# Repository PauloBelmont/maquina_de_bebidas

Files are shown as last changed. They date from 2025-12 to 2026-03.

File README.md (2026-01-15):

# Automated Coffee & Tea Machine (ESP32 + Nextion)

## 📚 About This Project

This project was developed at the **Federal University of Roraima (UFRR)**, in the **Maloca das iCoisas Laboratory**, as part of the course **COMP 923 - Embedded Systems**, under the guidance of [**Prof. Herbert Rocha**](https://github.com/hbgit).

---

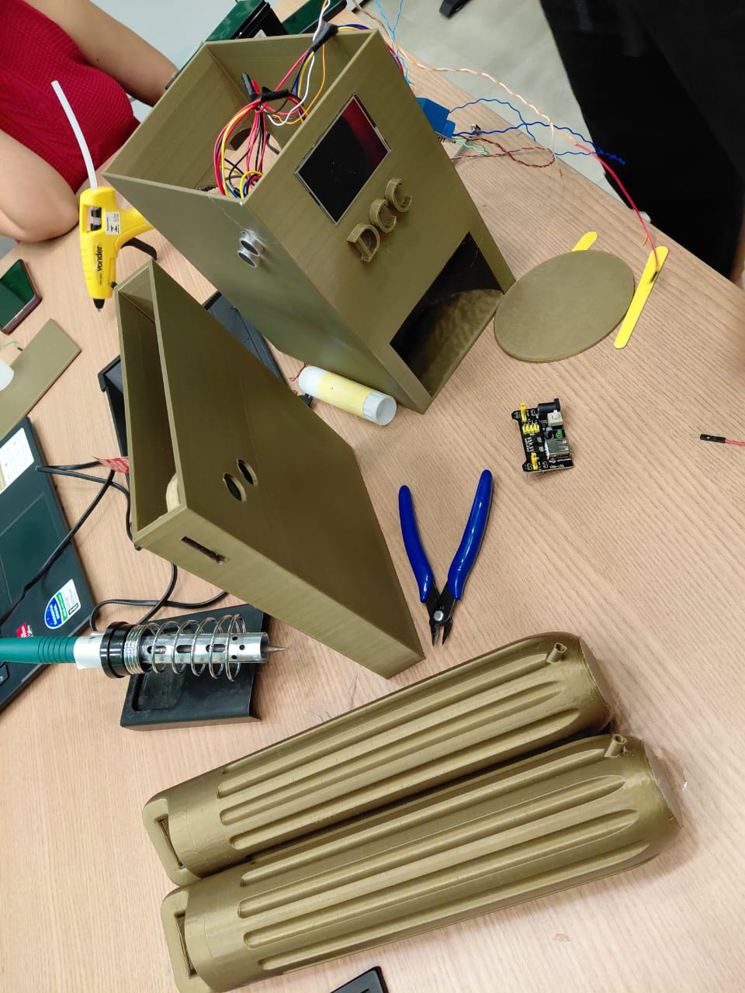
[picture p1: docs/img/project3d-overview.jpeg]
3D-printed coffee and tea vending machine prototype disassembled on a workbench, showing the main enclosure with screen and DCC logo, side panels, cylindrical reservoirs, wiring and assembly tools


This project is an embedded system for a hot beverage vending machine (coffee and tea). It uses an ESP32 for logic control, ultrasonic sensors for process detection, and a Nextion display for the Human-Machine Interface (HMI).

## 📂 Contents

The project directory structure is organized as follows:

* **`docs/`** - Project documentation, including requirements reports, circuit diagrams, and operation manuals.
* **`src/`** - Includes the Nextion interface project files (`.HMI`, `.tft`) and the source code (`.ino`) used on the ESP32.

## 🛠 Hardware

The physical project consists of the following components:

**Control & Interface**
* 1x ESP32 Devkit V1 Board
* 1x Nextion NX3224T024_011 Display (Touchscreen)

**Sensors & Actuators**
* 2x HC-SR04 Ultrasonic Sensors (Coin and Cup detection)
* 2x Peristaltic Pumps - Rohs Grothen G328
* 1x Relay Module SRD-05VDC-SL-C (Pump/Power control)

**Power & Structure**
* 1x Valve Regulated Lead-Acid (VRLA) Battery 12V
* 2x 3D Printed Cases (PLA) for main structure and coin mechanism
* 1x 3D Printed Plate (PLA)
* 2x 3D Printed Liquid Reservoirs (PLA)
* Hoses and Dispensing Nozzles

## Software Used

* **Arduino IDE:** For ESP32 firmware programming.
* **Nextion Editor (LTS):** For graphical interface development.
* **TinkerCad:** For 3D modeling and/or circuit simulation.
* **Doxygen:** For source code documentation.

## How it Works

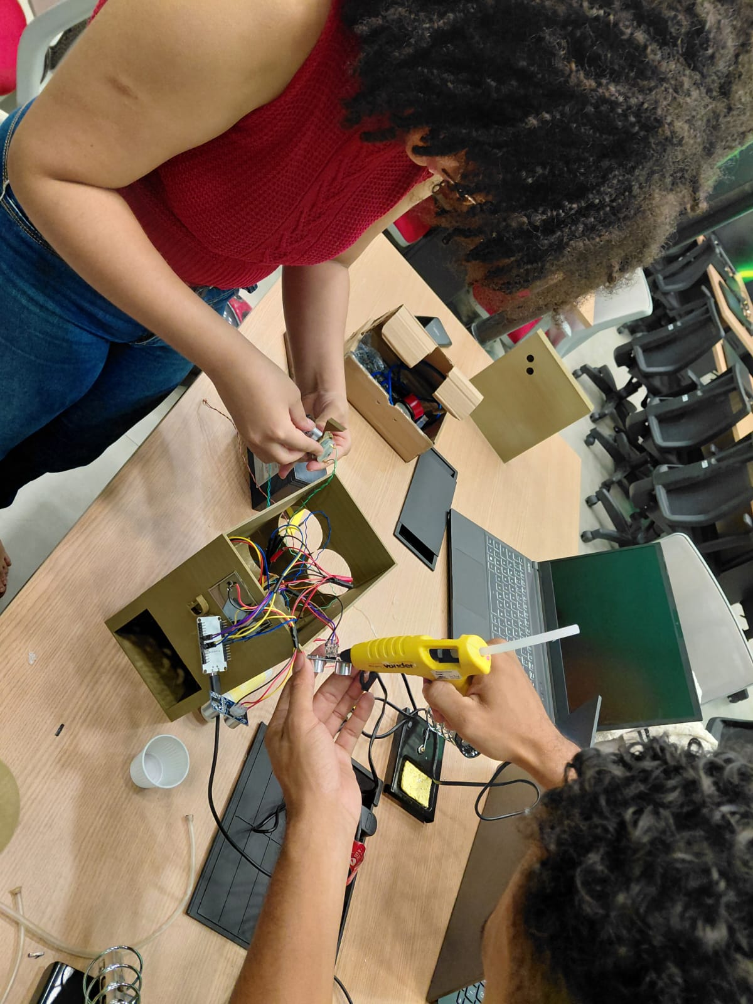
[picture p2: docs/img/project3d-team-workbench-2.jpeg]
Team members assembling the 3D-printed coffee machine structure and gluing components during the prototype build


The code operates based on a Finite State Machine (FSM), ensuring the process follows a safe logical order:

1.  **Start:** The system initializes and waits for a coin to be inserted.
2.  **Coin Insertion:** The HC-SR04 sensor (Pins X/Y) detects a coin drop.
3.  **Cup Placement:** The second HC-SR04 sensor (Pins X/Y) verifies a cup is in the dispenser.
4.  **Selection:** The user selects "Coffee" or "Tea" on the Nextion screen.
5.  **Preparation:** The corresponding pump is activated for a set duration , updating a progress bar on the screen.
6.  **Completion:** The system waits for the cup to be removed before resetting to the start state for a new cycle.

## 🔌 Pinout (ESP32)

| Component | ESP32 Pin | Function |
| :--- | :--- | :--- |
| **Coin Trig** | GPIO 32 | Coin Sensor Trigger |
| **Coin Echo** | GPIO 33 | Coin Sensor Echo |
| **Cup Trig** | GPIO 19 | Cup Sensor Trigger |
| **Cup Echo** | GPIO 18 | Cup Sensor Echo |
| **Coffee Relay** | GPIO 25 | Coffee Pump Activation |
| **Tea Relay** | GPIO 26 | Tea Pump Activation |
| **Nextion RX** | GPIO 16 | RX2 (Serial) |
| **Nextion TX** | GPIO 17 | TX2 (Serial) |

## Authors

- **Andersson Silva Pereira** — *andersonwya4@gmail.com*
- **Matheus Rebouças de Lima** — *mthsbusiness91@protonmail.com*
- **Paulo César Pereira Belmont** — *paulopereira737@hotmail.com*
- **Sarah Evelyn do Vale Silva** — *sarahevelyn.scholar@gmail.com*

## Additional Photos

More photos of the 3D-printed parts, internal circuits and assembly process are available in the [`docs/img/`](docs/img/) folder.

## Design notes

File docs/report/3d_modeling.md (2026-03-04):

# 3D Modeling Documentation (Tinkercad)

## 1. Main Enclosure (3D Model Assembly)
This section documents the main enclosure design, modeled entirely in Tinkercad. This 3D structure is the chassis designed to house the system's components, including mounting points for the UI, dispensing area, fluid routing, and internal supports.

### Purpose
The main enclosure integrates:
- The user interface (touchscreen opening).
- The dispensing window (cup insertion area).
- Internal mounts for reservoirs, pumps, and tube routing.
- The ultrasonic sensor used for coin detection (installed inside the main enclosure, aligned to detect the coin passing through the chute path).

### Images
| Top View / Internal Layout | Alternate Image |
| :---: | :---: |
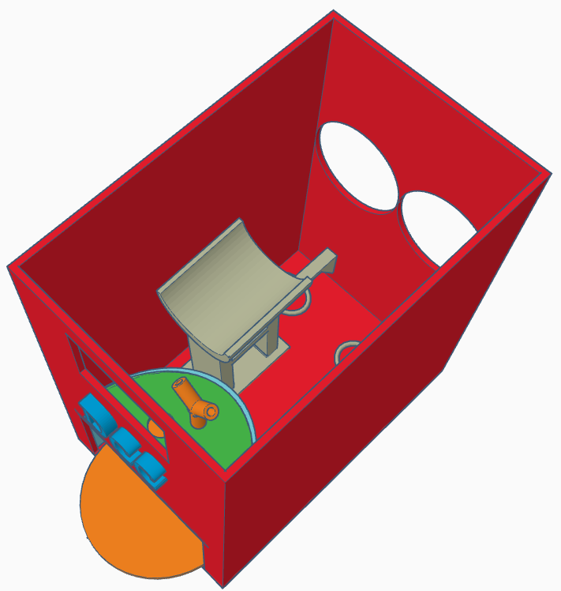
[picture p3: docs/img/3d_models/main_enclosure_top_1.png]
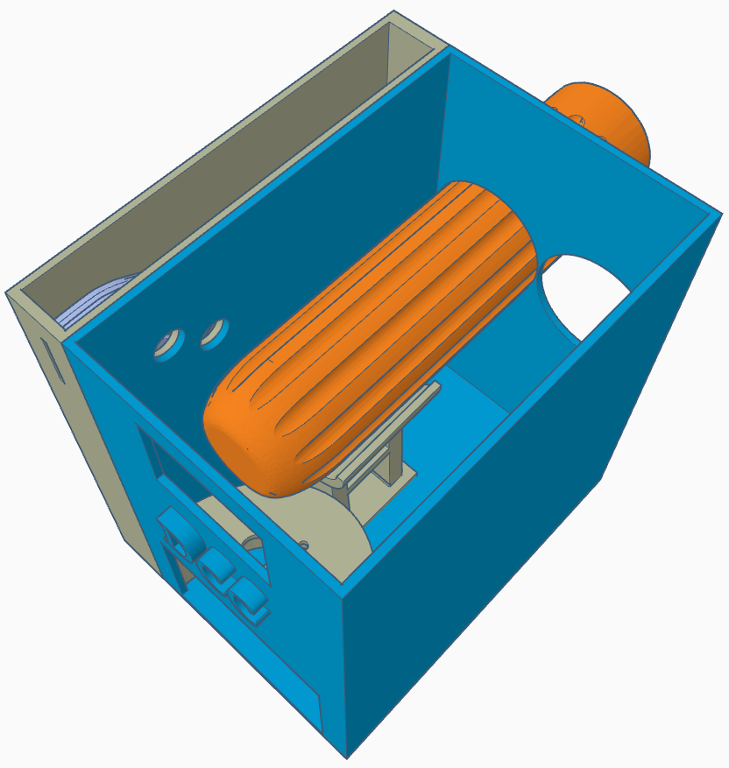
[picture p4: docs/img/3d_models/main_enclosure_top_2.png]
|  |  |

**Front View (UI & Dispensing Area):**
<div align="center">
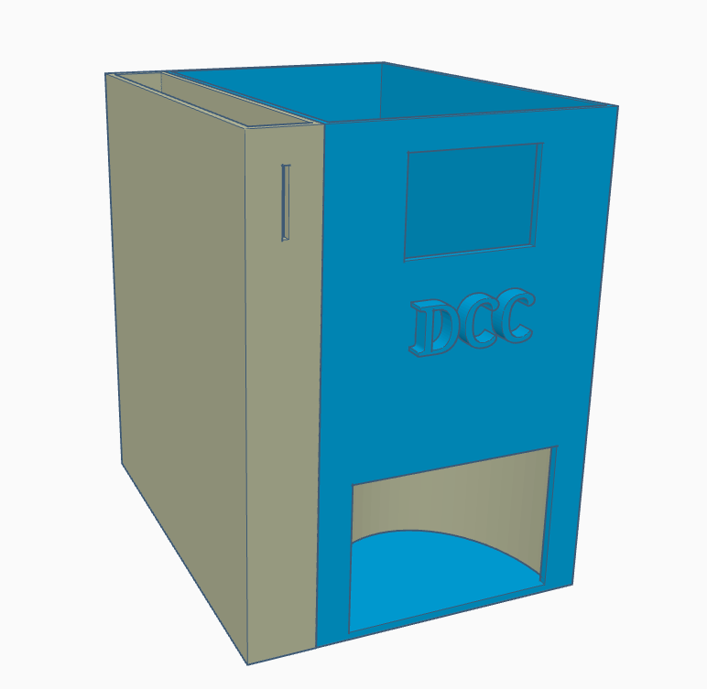
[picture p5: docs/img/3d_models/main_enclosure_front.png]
  
</div>

---

## 2. Coin Box Module (Side Module)
The coin box (side module) is the entry point for coins. It is physically attached to the main enclosure and is responsible for guiding the coin into the sensing region.

### Images
| External View | Internal View |
| :---: | :---: |
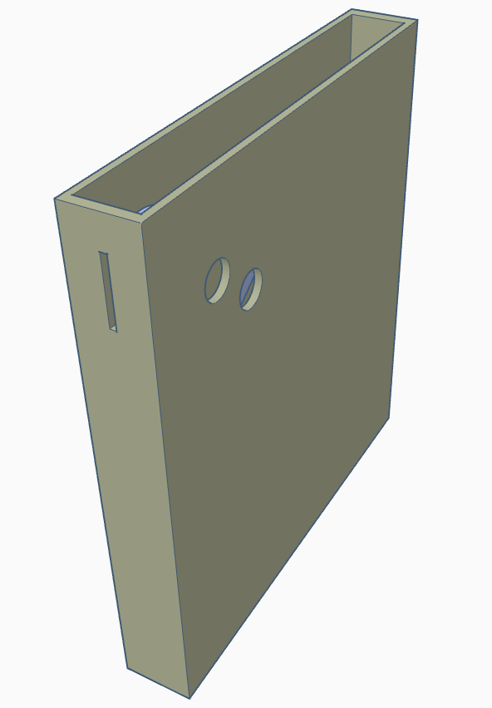
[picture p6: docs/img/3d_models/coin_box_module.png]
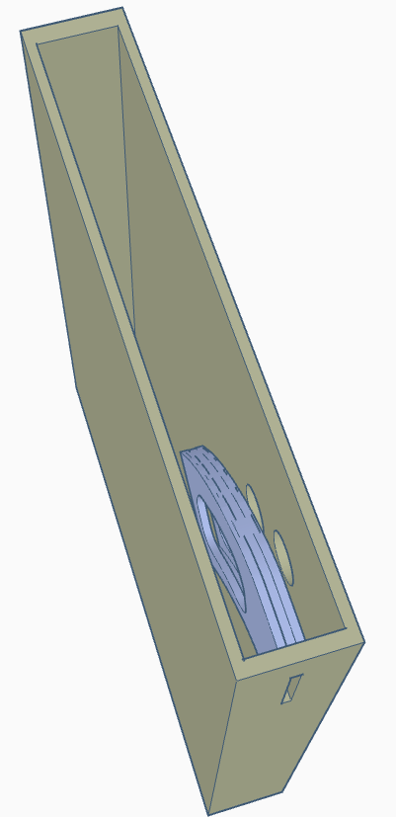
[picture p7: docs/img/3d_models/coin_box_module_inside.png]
|  |  |

---

## 3. Coin Chute ("Toboggan") + Coin Detection
Inside the coin box, a gravity-fed chute (toboggan) guides the coin along a controlled path. The chute is designed so that, as the coin slides down, it passes through a region where an ultrasonic sensor inside the main enclosure can detect it.

### Sensor Positioning
- The ultrasonic sensor used for coin detection is installed inside the main enclosure and is oriented at approximately **45°**, aimed toward the coin path to produce a reliable distance change when a coin passes.

### Images
| Front View | Side View |
| :---: | :---: |
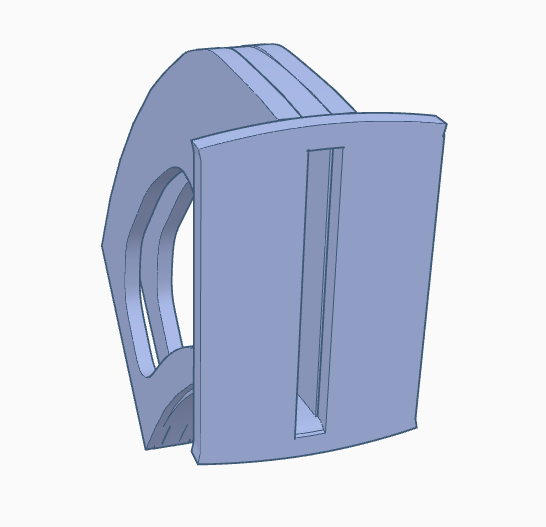
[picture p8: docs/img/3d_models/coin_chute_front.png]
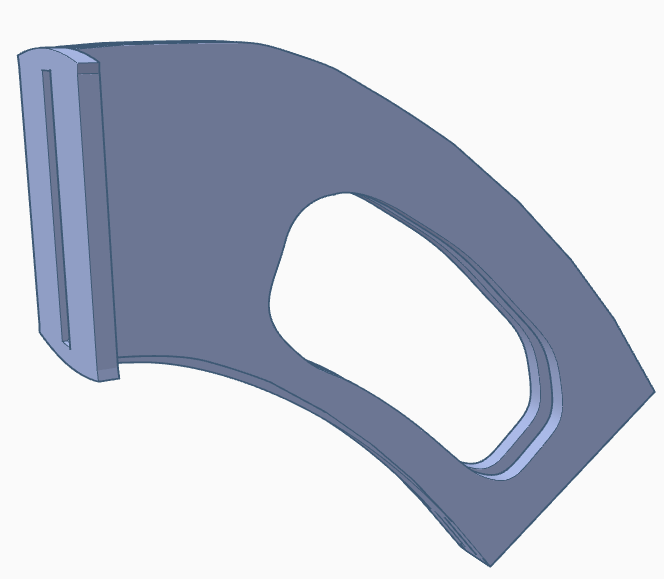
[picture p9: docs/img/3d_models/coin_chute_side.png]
|  |  |

---

## 4. Cup Insertion Area + Cup Base + Cup Presence Sensor
This subsystem guarantees correct cup positioning before dispensing and adds safety/automation by verifying cup presence.

### Cup Insertion (Dispensing Window)
The front-bottom opening is where the user inserts the cup. The geometry is designed to guide the cup into a stable dispensing position.

### Cup Base (Support Plate)
A base/plate is included to support the cup and keep it aligned under the outlet (Y-connector output).

### Cup Presence Ultrasonic Sensor (Top Hole)
A second ultrasonic sensor is used to detect whether a cup is present. A dedicated hole/opening is placed **on the upper part** of the cup insertion area to mount this sensor, facing the cup region.

### Images
**Cup Station & Y-Connector Alignment:**
<div align="center">
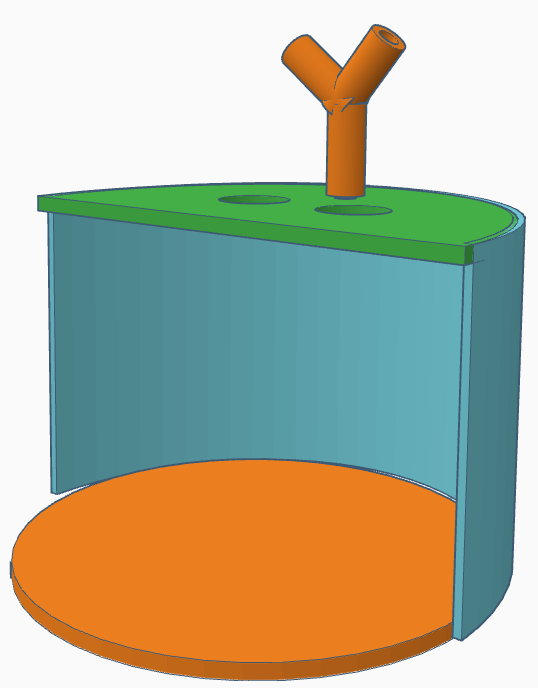
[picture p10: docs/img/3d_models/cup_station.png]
  
</div>

| Sensor Holes (Bottom View) | Rear View |
| :---: | :---: |
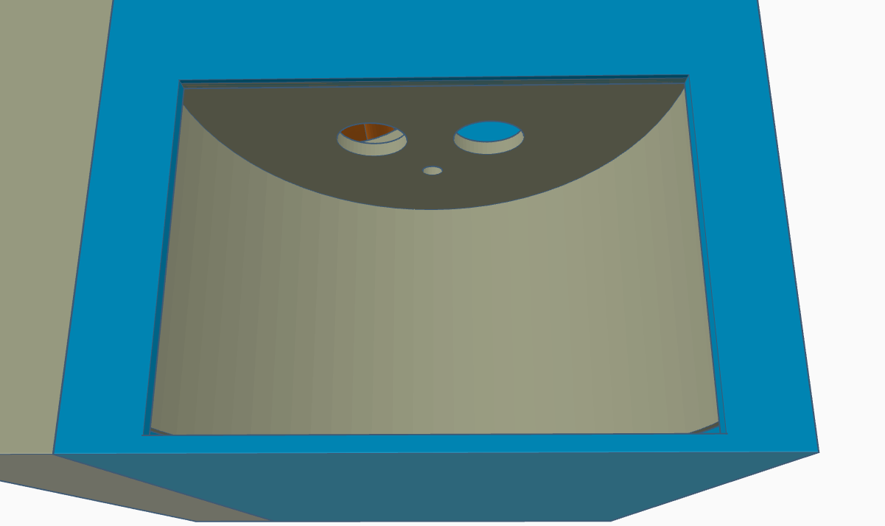
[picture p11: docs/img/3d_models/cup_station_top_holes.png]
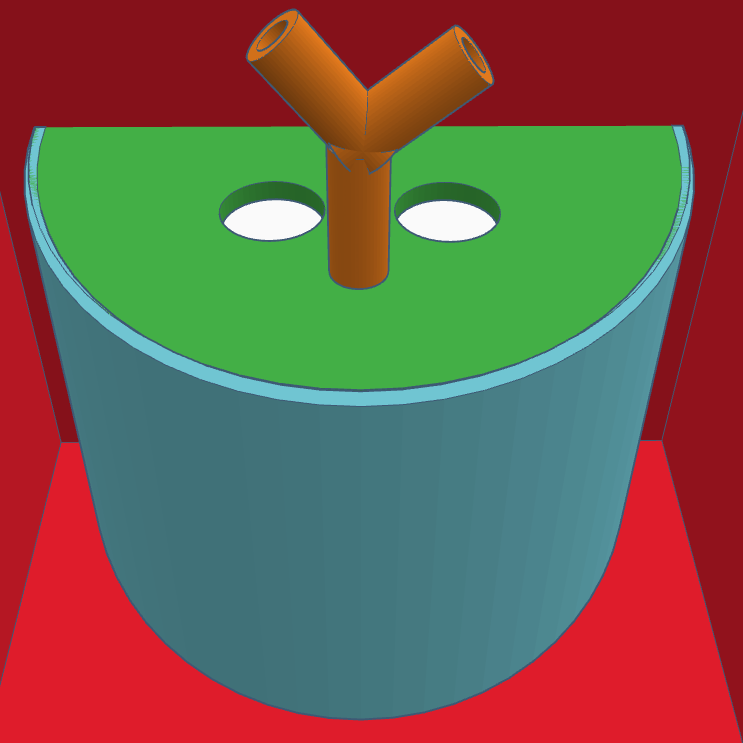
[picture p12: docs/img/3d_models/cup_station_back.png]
|  |  |

---

## 5. Y-Connector (Fluid Convergence and Alignment)
The Y-connector is a custom printed part that merges two fluid lines (tea and coffee) into a single outlet. It is positioned so the combined output falls precisely into the cup at the center of the cup station, minimizing splash and misalignment.

### Images
| Placement Overview | Internal Channel View |
| :---: | :---: |
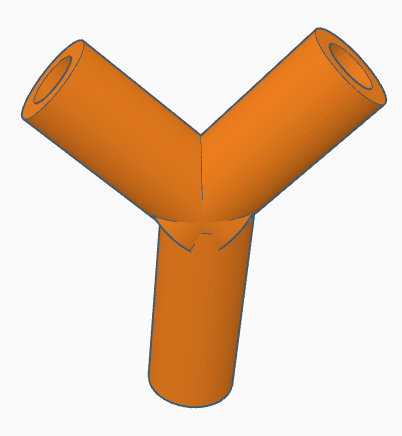
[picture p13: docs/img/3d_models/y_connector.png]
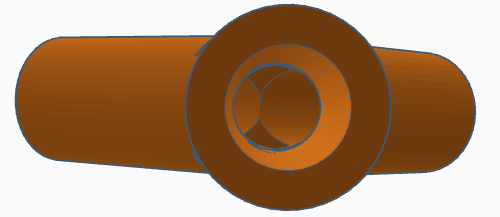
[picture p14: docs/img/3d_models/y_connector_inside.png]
|  |  |

---

## 6. Reservoir Support (Tea & Coffee Holders)
An internal support structure stabilizes the tea and coffee reservoirs.

### Images
| Structure Overview | Side Profile |
| :---: | :---: |
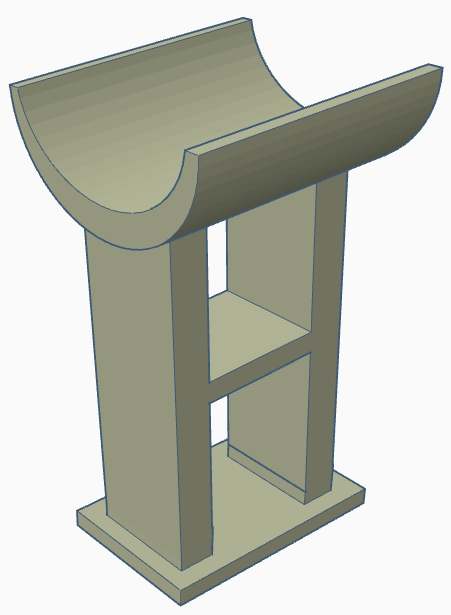
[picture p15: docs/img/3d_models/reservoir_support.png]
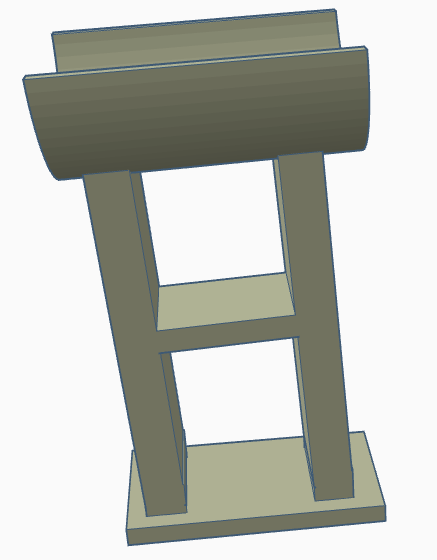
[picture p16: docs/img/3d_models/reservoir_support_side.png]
|  |  |

---

## 7. Pump Motor Mounts (Liquid Pump Supports)
Two smaller mounts are used to hold the pump motors responsible for pulling liquids from the reservoirs. These mounts constrain movement and reduce vibration, keeping tube routing stable and repeatable.

### Images
| Mount Isometric View | Mount Front View |
| :---: | :---: |
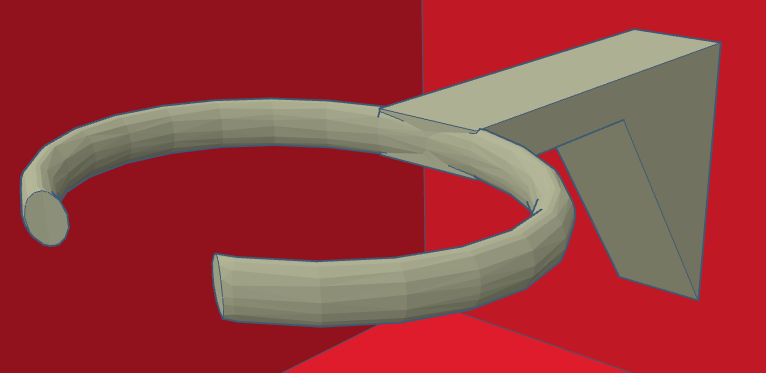
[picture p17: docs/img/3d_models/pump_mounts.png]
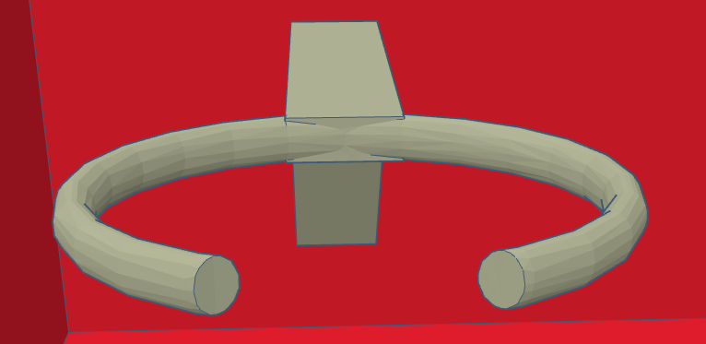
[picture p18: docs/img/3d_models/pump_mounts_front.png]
|  |  |

---

## 8. Coffee Liquid Reservoir (Inspired Design)
The coffee liquid reservoir was inspired by an existing model published on MakerWorld:
[https://makerworld.com/en/models/155504-keychain-container-pill-storage-bottle#profileId-836561](https://makerworld.com/en/models/155504-keychain-container-pill-storage-bottle#profileId-836561)

### Changes from the Original Model
- **Vertical Scaling:** The primary modification was increasing the height to expand fluid capacity.
- **Diameter Adjustment:** Both the top and bottom parts were adjusted to a diameter of **61 mm** to fit the machine's internal supports.
- The cap design and threading mechanism remain identical to the original author’s model.

### Notes
This design choice was made to increase usable volume while preserving the proven geometry of the original container (including its lid fit and mechanical structure).

### Images
| Top Part (Isometric) | Top Part (Top View) |
| :---: | :---: |
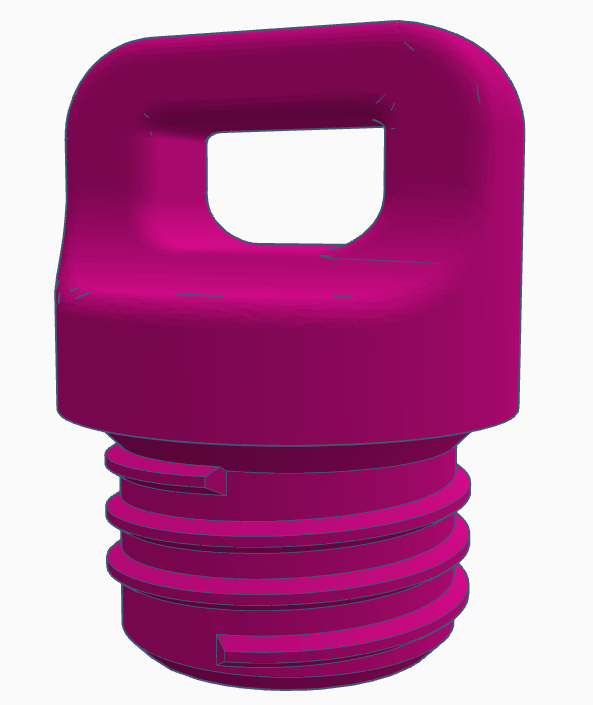
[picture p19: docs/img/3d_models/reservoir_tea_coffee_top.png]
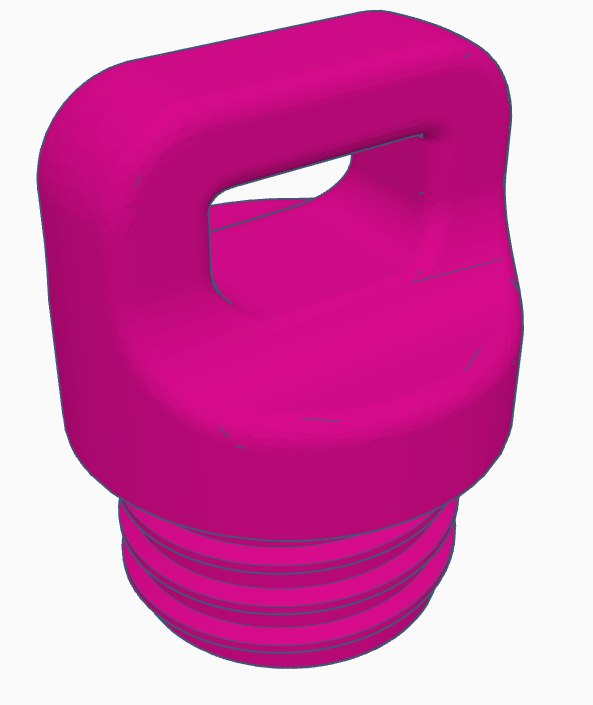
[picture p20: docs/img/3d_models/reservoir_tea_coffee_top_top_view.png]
|  |  |

| Bottom Part (Isometric) | Bottom Part (Top View) |
| :---: | :---: |
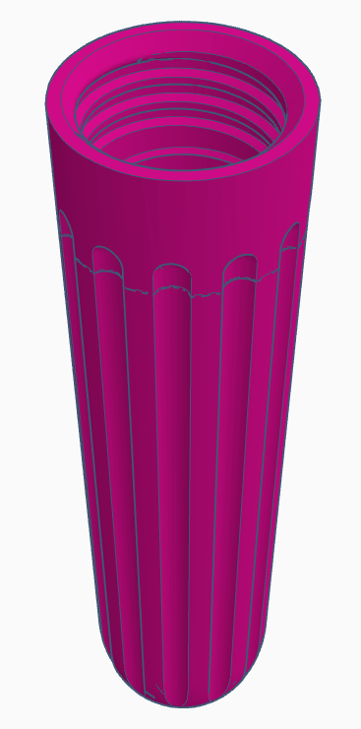
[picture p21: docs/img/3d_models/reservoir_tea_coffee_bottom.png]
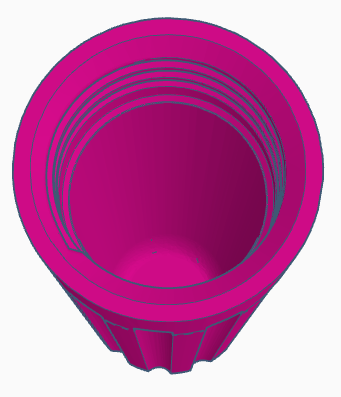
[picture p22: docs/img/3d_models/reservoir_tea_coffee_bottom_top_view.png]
|  |  |

---

## 9. Downloads (STL Files)
All the STL files necessary for 3D printing these components are available in the repository. You can find them in the following directory:

📂 **[3D Models Folder](../../src/stl/)**

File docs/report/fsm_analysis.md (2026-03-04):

# ⚙️ Finite State Machine (FSM) Analysis

**Project:** Automated Hot Beverage Machine
**Module:** Firmware Logic (ESP32)

## 1. Overview

The system control logic is implemented using a **Finite State Machine (FSM)**. This approach ensures that the machine is always in a known, deterministic state, preventing invalid operations (e.g., pouring coffee without a cup or dispensing two drinks for one coin).

The FSM manages the entire lifecycle of a transaction: from initialization and coin detection to beverage dispensing and system reset.

***

## 2. State Diagram Representation

The following diagram represents the logical flow implemented in the firmware:

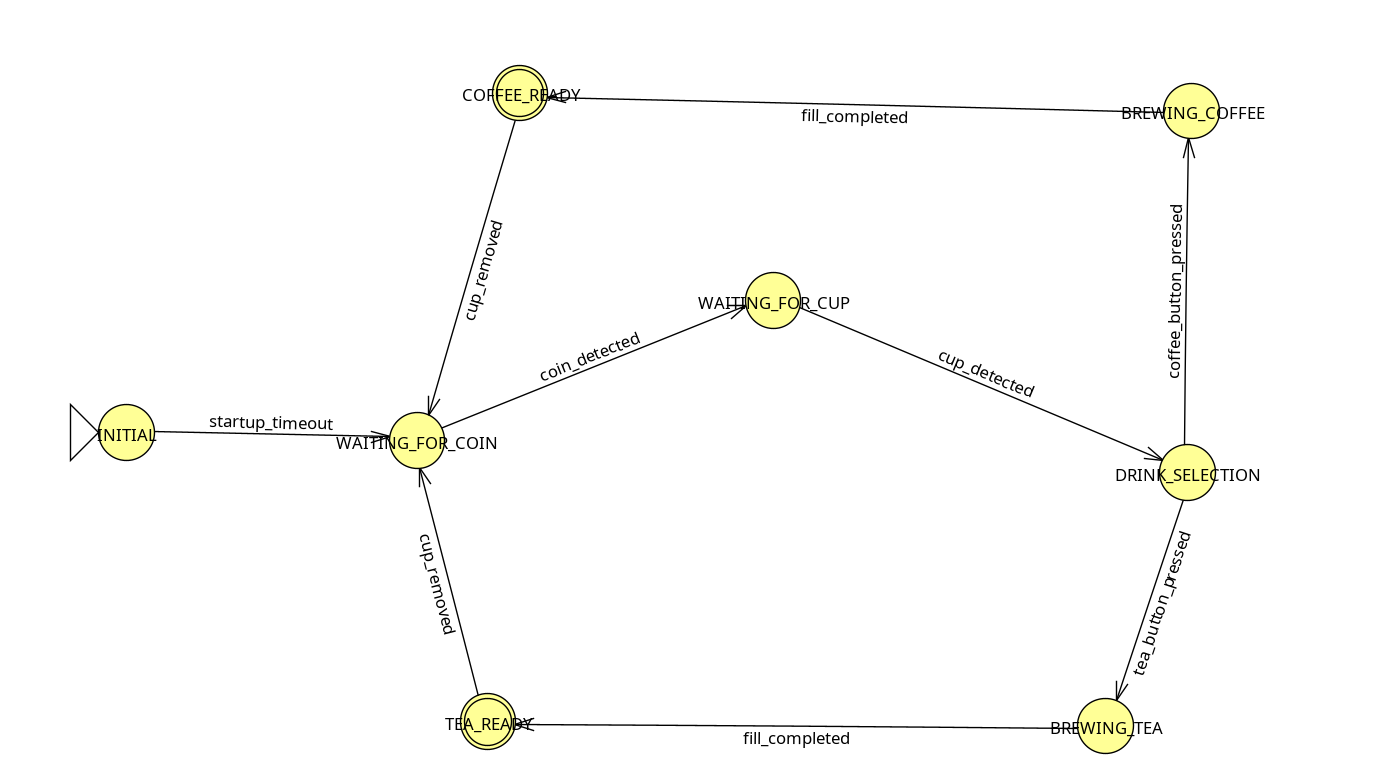
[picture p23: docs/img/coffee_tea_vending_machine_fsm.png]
State Machine Diagram showing the transition flow from initialization to coin detection, cup verification, drink selection, and final dispensing loop


***

## 3. Detailed State Definitions

The system consists of **7 distinct states**. Each state defines specific active sensors and permitted actions.

| State Name | Description | Active Hardware / Output |
| :--- | :--- | :--- |
| **INITIAL** | System boot, variable initialization, and sensor calibration. | Display: "Initializing..." |
| **WAITING_FOR_COIN** | The machine is idle, waiting for a user to insert a coin (token). | Sensor: Ultrasonic 1 (Coin) <br> Display: "Insert Coin" |
| **WAITING_FOR_CUP** | A coin was validated. System now waits for a cup to be placed in the dispenser area. | Sensor: Ultrasonic 2 (Cup) <br> Display: "Place Cup" |
| **DRINK_SELECTION** | Cup is present. The system unlocks the touchscreen for beverage choice. | Input: Nextion Touch (UART) <br> Display: "Select Drink" |
| **BREWING_COFFEE** | The pump for Coffee is active for a calibrated duration. | Actuator: Pump 1 (ON) <br> Display: "Brewing Coffee..." |
| **BREWING_TEA** | The pump for Tea is active for a calibrated duration. | Actuator: Pump 2 (ON) <br> Display: "Brewing Tea..." |
| **COFFEE/TEA_READY** | Dispensing is done. System waits for the user to take their drink before resetting. | Sensor: Ultrasonic 2 (Cup) <br> Display: "Enjoy!" |

***

## 4. Transition Logic Table

Transitions are triggered by specific **events** (sensor readings, timers, or user inputs).

| Current State | Event / Condition | Next State | Justification |
| :--- | :--- | :--- | :--- |
| `INITIAL` | `startup_timeout` (e.g., 3s) | `WAITING_FOR_COIN` | Allows sensors to stabilize before reading. |
| `WAITING_FOR_COIN` | `coin_detected` (Distance < Threshold) | `WAITING_FOR_COIN` | Payment validated. Proceed to preparation. |
| `WAITING_FOR_CUP` | `cup_detected` (Distance < Threshold) | `DRINK_SELECTION` | Safety check: Ensures a container is present. |
| `DRINK_SELECTION` | `coffee_button_pressed` (UART 'A') | `BREWING_COFFEE` | User choice: Coffee. |
| `DRINK_SELECTION` | `tea_button_pressed` (UART 'B') | `BREWING_TEA` | User choice: Tea. |
| `BREWING_COFFEE` | `fill_completed` (Timer) | `COFFEE_READY` | Volumetric control by time (e.g., 5000ms). |
| `BREWING_TEA` | `fill_completed` (Timer) | `TEA_READY` | Volumetric control by time. |
| `COFFEE/TEA_READY` | `cup_removed` (Distance > Threshold) | `WAITING_FOR_COIN` | Reset cycle for next customer. |

***

## 5. Safety & Reliability Features

The FSM implementation provides critical safety mechanisms:

1.  **Interlock Safety:** It is impossible to activate a pump (Dispensing state) directly from the Idle state. The path *must* include Coin Validation → Cup Verification.
2.  **Spill Prevention:** The `WAITING_FOR_CUP` state acts as a physical barrier. If a user inserts a coin but forgets the cup, the machine waits indefinitely and does not dispense liquid into the tray.
3.  **Debouncing:** Sensor transitions (like `coin_detected`) typically implement software debouncing to prevent false positives from sensor noise.
4.  **Sequential Reset:** The machine only returns to `WAITING_FOR_COIN` after the previous user has removed their finished drink (`cup_removed`), preventing the next user from accidentally interacting with a finished cycle.

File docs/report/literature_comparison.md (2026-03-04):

# 📚 Comparative Literature Review

The following section presents **two comparative tables**:

1.  **Commonalities** shared across all four analyzed articles.
2.  **Key Differences** distinguishing each approach.

For clarity, the articles are identified as follows:

*   **A1** – Innovation Station (3D printing vending machine)
*   **A2** – Didactic Vending Machine (Arduino-based)
*   **A3** – Energetically Efficient Vending Machine
*   **A4** – RPJ 2014 (Vending/Mechatronic systems)

***

## 🔹 Table 1 — Commonalities Across All Articles

| Common Point | Description |
| :--- | :--- |
| **Vending Machine Usage** | All projects utilize a vending machine structure as the system baseline. |
| **Process Automation** | Product dispensing is fully automated. |
| **Mechatronic Integration** | They combine mechanics, electronics, and software engineering. |
| **Embedded Systems** | Use of microcontrollers or computational control units. |
| **Physical Prototyping** | All papers present functional physical prototypes. |
| **Modeling & Simulation** | Utilization of simulation, CAD, or virtual modeling tools. |
| **Focus on Innovation** | Proposals offer improvements over traditional vending machines. |
| **Efficiency Analysis** | Evaluation of performance, consumption, reliability, or optimization. |
| **Practical Application** | The systems are designed for deployment in real-world environments. |
| **Academic Approach** | The projects possess a scientific or educational character. |

**Sources:** A1, A2, A3, and A4

***

## 🔹 Table 2 — Differences Between Articles

| Article | Primary Objective | Key Differentiator | Focus Area |
| :--- | :--- | :--- | :--- |
| **A1** | Democratize 3D printing | Automatic removal via thermal cycling + Web portal | Additive manufacturing & Education |
| **A2** | Engineering education | Arduino, SMS stock alerts, change return system | Embedded systems & Didactics |
| **A3** | Energy sustainability | Solar power supply & consumption optimization | Energy efficiency & Mechatronics |
| **A4** | Technical/Industrial app | Emphasis on reliability and control logic | Industrial automation |

**Sources:** A1, A2, A3, and A4

***

## 🔹 Quick Interpretation

*   All articles address **automated vending machines**, but with distinct focuses:
    *   **A1** focuses on **3D printing accessibility**.
    *   **A2** focuses on **teaching with Arduino**.
    *   **A3** focuses on **renewable energy and efficiency**.
    *   **A4** focuses on **industrial robustness**.

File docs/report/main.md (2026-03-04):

# Technical Report

Project: Automated Hot Beverage Machine (Coffee and Tea)
========================================================

<h3>Repository: <a href="https://github.com/PauloBelmont/maquina_de_bebidas">PauloBelmont/maquina_de_bebidas</a></h3>

**Authors:** Andersson Silva Pereira, Matheus Rebouças de Lima, Paulo César Pereira Belmont, Sarah Evelyn do Vale Silva ([GitHub][1])
**License:** MIT ([GitHub][1])
**Date:** *January / 2026*
**CAPES Category:** Prototype, system, artifact, or computational process with functional validation.

**Report Objective:** Document technological architecture, innovation, components, and system operation.

**Justification:**

- Functional embedded system, not merely conceptual;
- Integrates hardware–software integration;
- Possesses technical documentation (report, UML diagrams, architecture);
- Is reproducible and subject to experimental validation.

---

## 📌 1. Project Overview

The &quot;<b>Automated Hot Beverage Machine</b>&quot; project consists of an **embedded system for autonomous acquisition and preparation of hot beverages** (coffee and tea), integrating sensors, actuators, and human-machine interface (HMI). The system was developed with focus on educational applications and rapid prototyping in the context of embedded systems.

---

## 📐 2. Solution Scope

This technical report addresses:

* **Technological architecture** of the system (hardware and software);
* **Control methods and user interface**;
* **Technical innovation and technological differentiation**;
* **Relevance for R&D&I**;
* **Conclusions and evolution recommendations**.

---

### 📚 2.1 Related Work & Theoretical Analysis

To validate the architectural decisions of this project, a comparative study was conducted against four academic references (A1-A4), analyzing commonalities in embedded automation and differences in application scope (3D printing, education, energy efficiency).

*   **[📄 Read the Full Literature Comparison](literature_comparison.md)**

Furthermore, the core control logic relies on a Finite State Machine (FSM). A detailed analysis of states, transitions, and safety conditions is available in the dedicated analysis document.

*   **[⚙️ Read the FSM Logic Analysis](fsm_analysis.md)**

---

## 🏗️ 3. Technological Architecture

### 🔌 3.1 Hardware

The machine utilizes a hybrid architecture combining electronic modules, detection sensors, and user interface:

| Component | Primary Function |
| --- | --- |
| **ESP32 Devkit V1** | Main control unit (MCU) |
| **Display Nextion NX3224T024_011** | Graphical interface and touchscreen (HMI) |
| **Ultrasonic Sensors HC-SR04** | Coin insertion and cup presence detection |
| **Peristaltic Pumps** | Precise liquid dispensing |
| **Relay Module SRD-05VDC-SL-C** | Pump control / power management |
| **Power Supply (12V Battery)** | System power |
| **3D-Printed Reservoirs** | Physical liquid storage |

**Integration Description:**
The **ESP32** orchestrates all modules, receiving sensor signals and commanding dosage pumps, ensuring the machine's operation cycle executes sequentially and safely. Event detection (such as coin insertion or cup presence) is performed by ultrasound, executing periodic readings and activations according to defined states.

---

### 🧠 3.2 Software

#### 🗂️ 3.2.1 Firmware (ESP32)

The firmware is **developed in C++ for the ESP32**, with logic based on **Finite State Machine (FSM)** to control operation phases:

1. **Initialization:** sensor and display setup
2. **Coin awaiting:** ultrasonic sensor detects insertion
3. **Cup detection:** second sensor reading
4. **Beverage selection:** via touchscreen interface
5. **Dispensing:** activation of corresponding pump
6. **Cycle completion:** cup removal detection and reset

This state pattern improves safety and reliability of the preparation process.

---

### 🎨 3.2.2 Human-Machine Interface (Nextion)

The graphical interface is designed to:

* Enable intuitive beverage selection;
* Display user feedback (e.g., progress, error messages);
* Connect via UART serial to the ESP32.

The use of **Nextion** display facilitates building complex interfaces without overloading the main microcontroller.

---

## 🚀 4. Technological Innovation

This project presents innovative aspects for educational applications and prototyping:

### ✓ Finite State Machine (FSM) Usage

FSM adoption organizes control flow and ensures robustness against asynchronous events, an essential factor in reactive embedded systems.

---

### ✓ Ultrasonic Sensing

The use of **ultrasonic sensors for coin and cup detection** is more precise and less susceptible to failures than simple mechanical switches.

---

### ✓ Agile Interface with Nextion

The separation between control (ESP32) and graphical interface (Nextion) is an architectural characteristic that **improves modularity and scalability**, especially when compared with systems implementing UI directly in firmware.

---

### ✓ 3D Printing Applied to Prototyping

The use of **3D-printed components** for physical structure enables rapid adjustments and design customization, a differentiator for R&D of interactive prototypes and IoT systems.

---

## 📈 5. Innovation Characteristics and Impact

This project demonstrates **an advance in teaching embedded systems and sensory integration with actuators**. Furthermore:

* ESP32 use incorporates future connectivity (Wi-Fi/Bluetooth) for telemetry or remote control;
* Architectural modularity facilitates evolution (e.g., NFC payment, cloud integration, consumption tracking, real-time dashboards);
* Can evolve into a minimum viable product in commercial environments or events.

This foundation is comparable to beverage automation trends, where intelligent autonomous systems address automated preparation and dispensing solutions — technically relevant in the current context of automation and services. ([TecMundo][2])

---

## 🧩 6. Conceptual Diagram (Text)

```
[Ultrasonic Sensor 1]       [Ultrasonic Sensor 2]
           │                        │
           └──────> ESP32 MCU <─────┘
                    │   ↓   ↑
                    │    Nextion Display
                    ↓
           [Power Relay] ──→ [Peristaltic Pumps]
                    ↓
              Dispensing System
```

## 🔄 7. System Architecture Diagram

```
┌─────────────────────────────────────────────────────┐
│              ESP32 Firmware (FSM)                   │
│  ┌──────────┐  ┌──────────┐  ┌──────────┐          │
│  │ Sensor   │  │ Actuator │  │ Serial   │          │
│  │ Manager  │  │Controller│  │ Comm     │          │
│  └──────────┘  └──────────┘  └──────────┘          │
└────────┬──────────────┬──────────────┬──────────────┘
         │              │              │
    ┌────▼─┐       ┌────▼──┐      ┌───▼────┐
    │Sensors│      │Relay  │      │Nextion │
    │(HC-   │      │Module │      │Display │
    │SR04)  │      │       │      │(UI)    │
    └───────┘      └───┬───┘      └────────┘
                       │
                   ┌───▼─────┐
                   │ Pumps   │
                   │(Liquid) │
                   └─────────┘
```

**Componentes:**
- **ESP32:** Orquestra sensores e atuadores via FSM
- **Sensores Ultrassônicos:** Detectam moedas e xícara
- **Módulo Relé:** Controla ativação das bombas
- **Display Nextion:** Interface gráfica via UART

## 8. Sequence Diagram (Main Scenario)

```
mermaid
sequenceDiagram
    ```
    mermaid
    sequenceDiagram
        participant U as User
        participant D as Nextion Display
        participant E as ESP32
        participant S as Sensors
        participant P as Pump

        U ->> D: Interacts with interface
        S ->> E: Coin detected
        E ->> D: Requests cup insertion
        S ->> E: Cup detected
        U ->> D: Selects Coffee
        D ->> E: Sends command
        E ->> P: Activates coffee pump
        P -->> E: Dispensing completed
        E ->> D: Displays final message
    ```
```

---

## 🧪 9. Technical Evaluation

### ✔ Strengths

* Modularity between control and interface;
* Detection robustness and operation cycle;
* Potential for IoT extension;
* Software pattern usage (FSM).

### ⚠ Limitations

* Lack of integration with modern payment methods;
* Absence of transaction logging or telemetry;
* Current scope limited to educational prototype.

---

## 📌 10. Recommendations for Evolution

| Future Improvements | Expected Benefits |
| --- | --- |
| **NFC Payment** | Modernizes usage and accessibility  |
| **Cloud Connectivity** | Telemetry and consumption dashboards|
| **Mobile App Control** | Remote interaction and personalization|
| **Machine Learning** | Stock prediction or recommendation  |

---

## 🏁 11. Conclusion

The **Automated Beverage Machine** project is a solid example of embedded systems prototyping with **sensory integration, reactive control, and user-friendly interface**. Its modular technological architecture and use of emerging technologies make it a relevant case for **R&D&I in IoT, physical automation, and advanced prototyping**.

---

## 📚 12. References

1. Project GitHub repository: *PauloBelmont/maquina_de_bebidas* – README and code structure. ([GitHub][1])
2. Articles on ultrasonic sensors and FSM in embedded systems.
3. Comparison with autonomous beverage machines and automation trends. ([TecMundo][2])

---

[1]: https://github.com/PauloBelmont/maquina_de_bebidas "GitHub - PauloBelmont/maquina_de_bebidas: Este repositório contém todos os artefatos relacionados ao projeto maquina de chafé"
[2]: https://www.tecmundo.com.br/tecnologia/47158-10-bartenders-robos-que-fazem-drinks-tao-bem-quanto-os-humanos.htm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 "10 bartenders robôs que fazem drinks tão bem quanto os humanos | Internet"

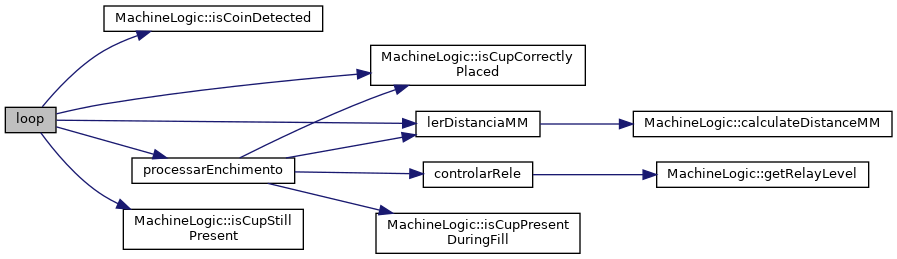
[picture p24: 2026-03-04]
docs/doxygen_output/html/dc/d3c/main_8ino_a0b33edabd7f1c4e4a0bf32c67269be2f_cgraph.png

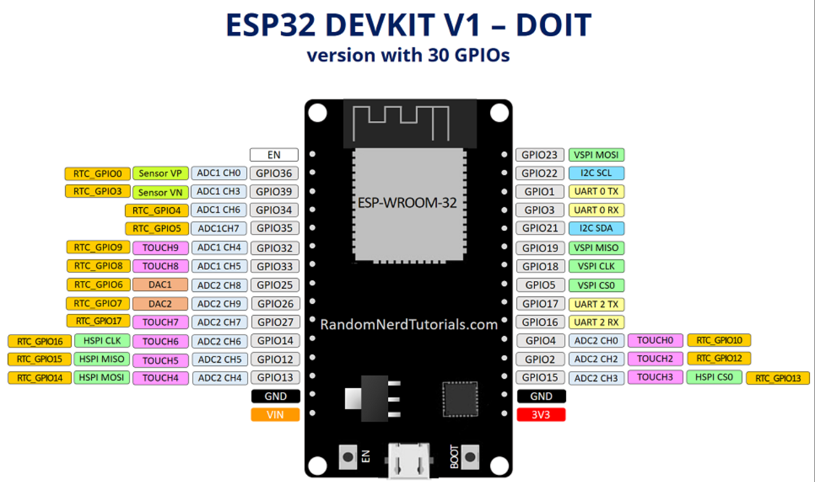
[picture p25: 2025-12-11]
src/esp/assets/portmap_esp32_devkit_v1.png

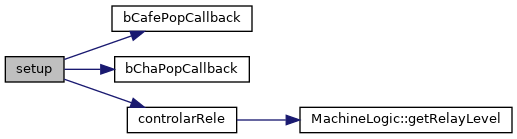
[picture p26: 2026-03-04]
docs/doxygen_output/html/dc/d3c/main_8ino_a7dfd9b79bc5a37d7df40207afbc5431f_cgraph.png

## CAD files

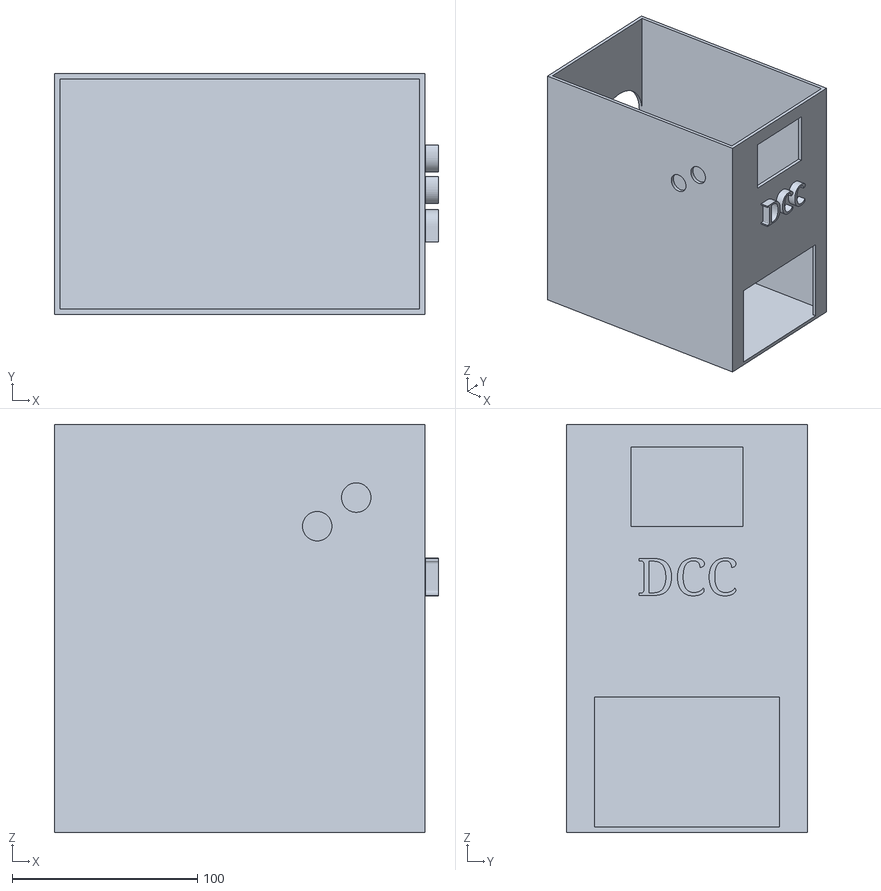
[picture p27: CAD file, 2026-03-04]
src/stl/main_enclosure_bottom.stl
207.2 x 130.0 x 220.0

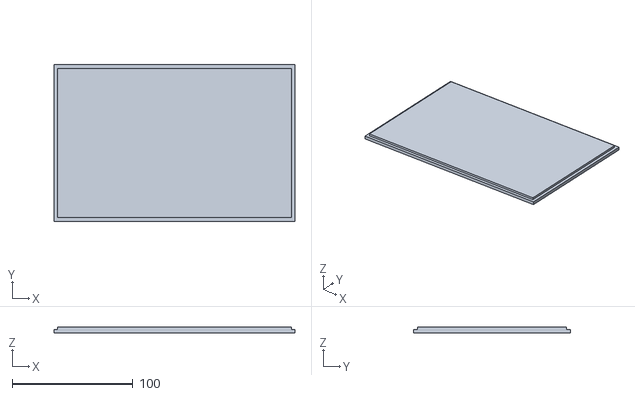
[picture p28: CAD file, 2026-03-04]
src/stl/main_enclosure_top.stl
200.0 x 130.0 x 5.00

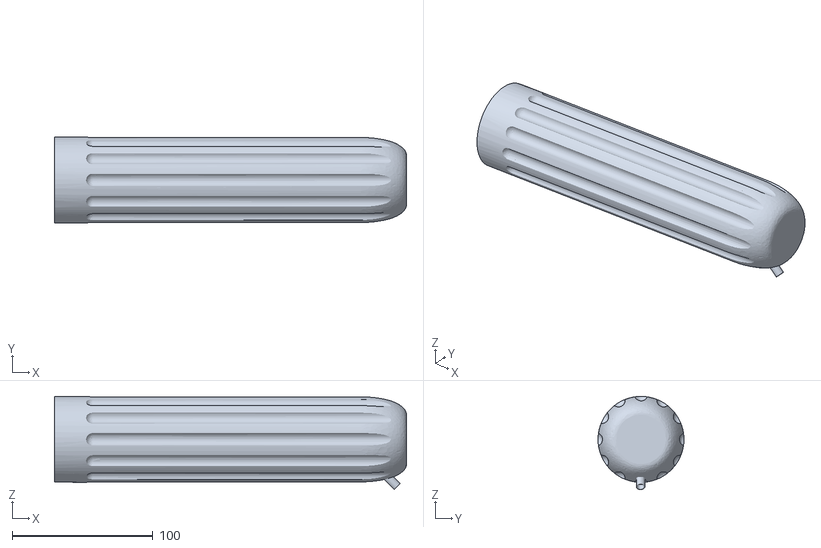
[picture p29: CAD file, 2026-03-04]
src/stl/Container_bottom_61mm.stl
249.8 x 61.0 x 66.2

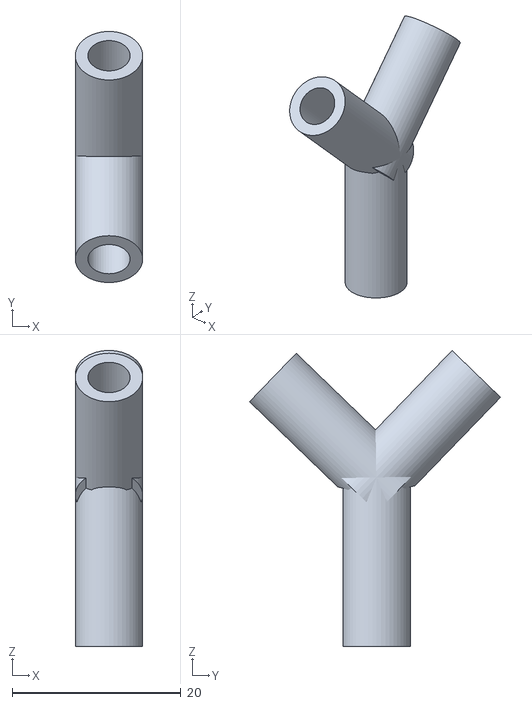
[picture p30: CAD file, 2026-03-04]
src/stl/y-connector.stl
8.00 x 29.8 x 35.1

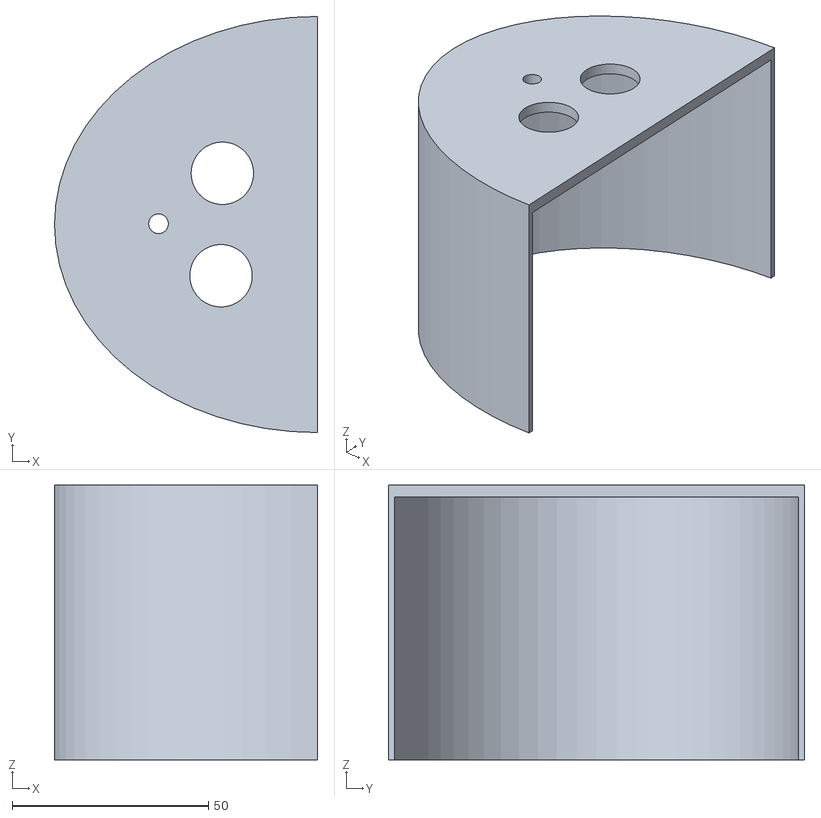
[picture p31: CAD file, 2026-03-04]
src/stl/cup_station.stl
67.0 x 106.0 x 70.0

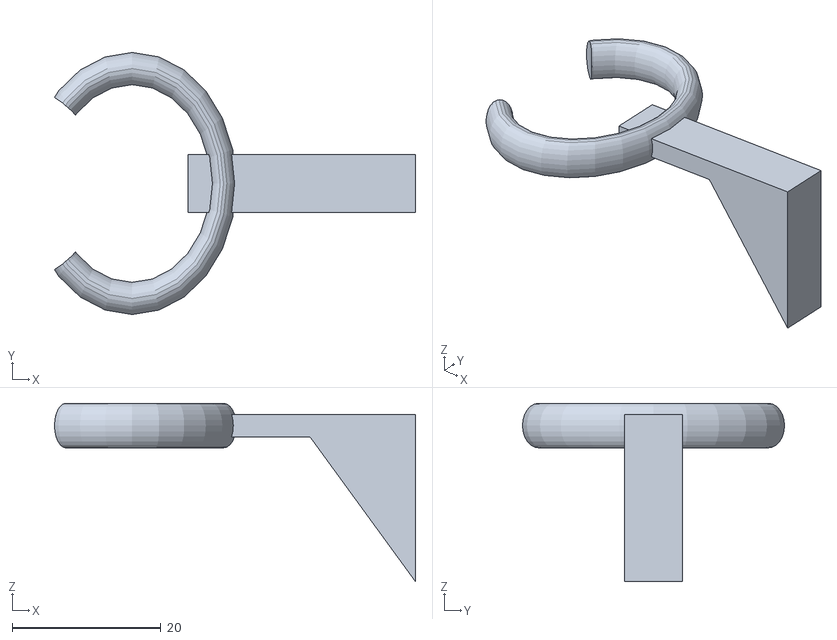
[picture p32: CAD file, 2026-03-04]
src/stl/pump_mount.stl
48.6 x 35.3 x 24.0

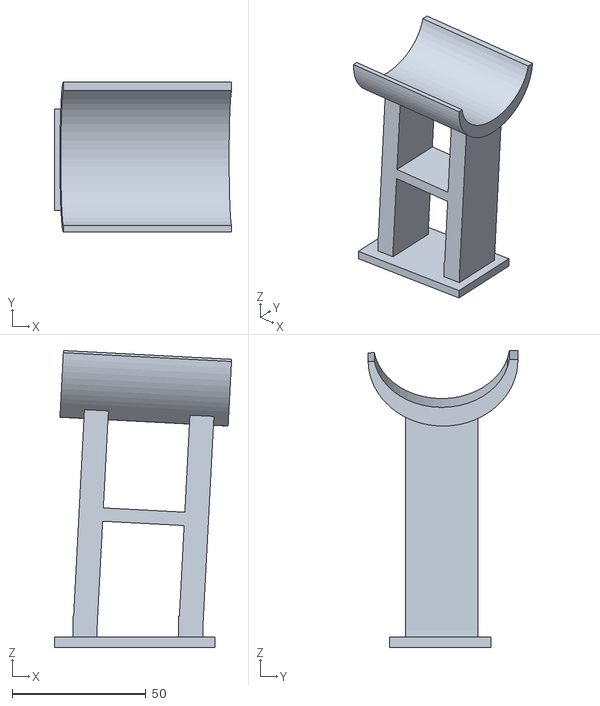
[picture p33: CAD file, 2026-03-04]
src/stl/Container_support.stl
66.3 x 56.0 x 111.1

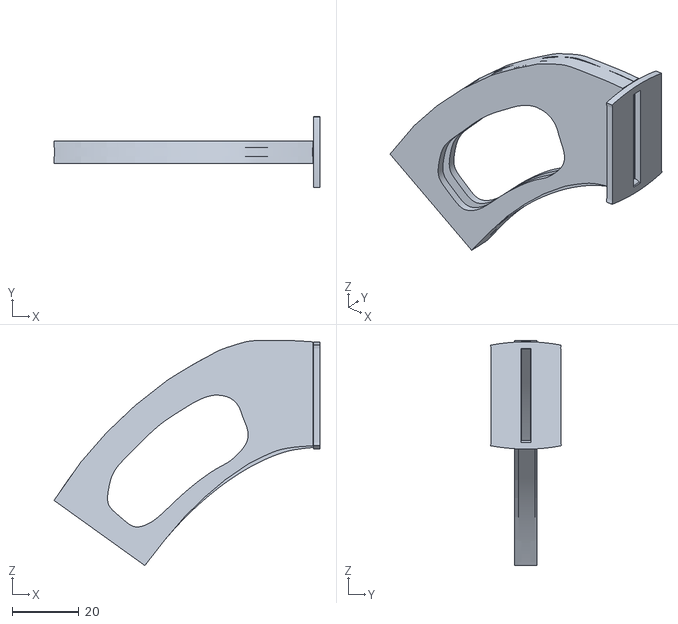
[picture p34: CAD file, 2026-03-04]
src/stl/coin_chute.stl
79.8 x 21.3 x 67.5

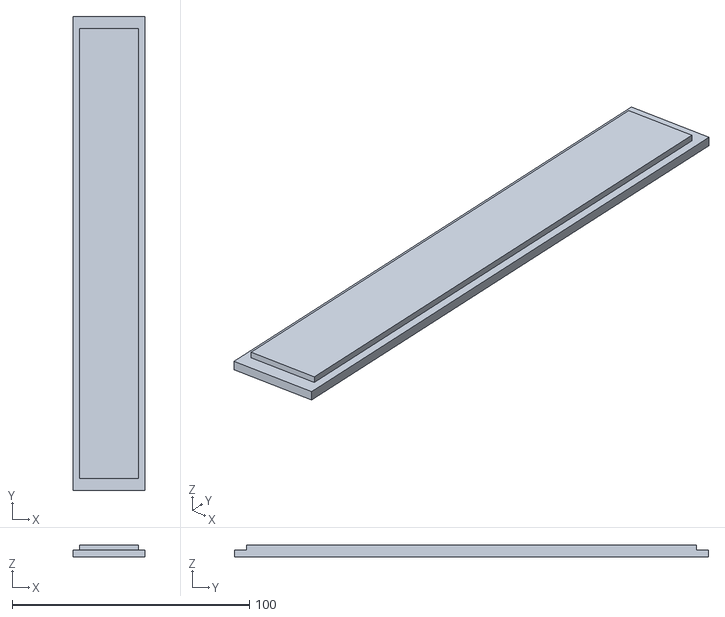
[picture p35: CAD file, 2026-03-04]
src/stl/coin_box_module_top.stl
30.5 x 200.0 x 5.00

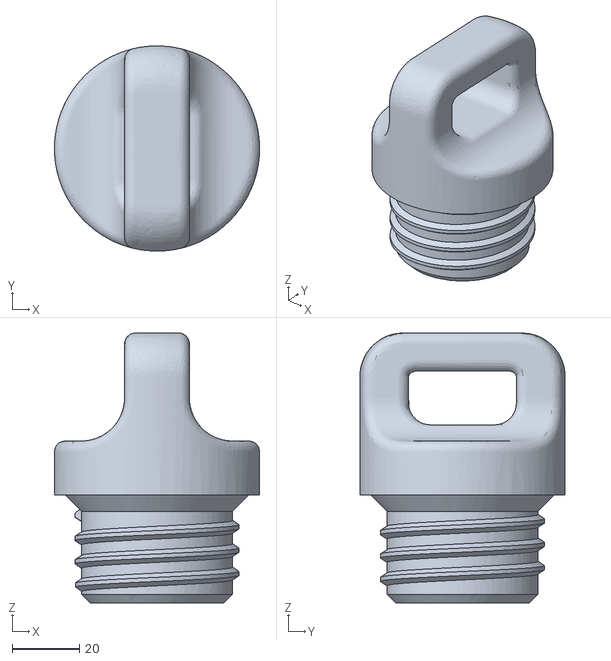
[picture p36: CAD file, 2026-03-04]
src/stl/Container_top_61mm.stl
61.0 x 61.0 x 80.3

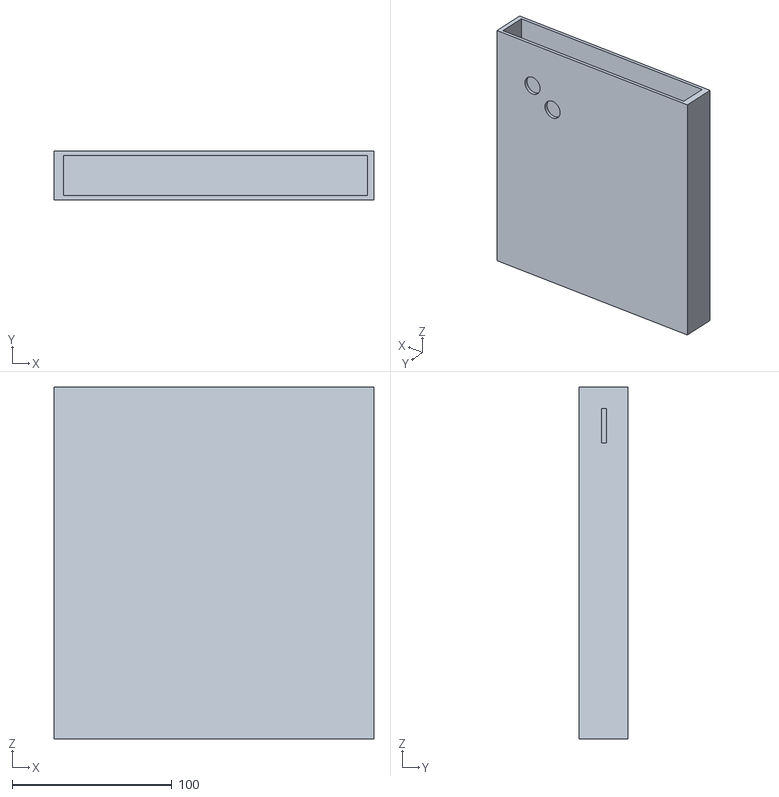
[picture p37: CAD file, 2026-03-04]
src/stl/coin_box_modulo_bottom.stl
200.0 x 30.5 x 220.0

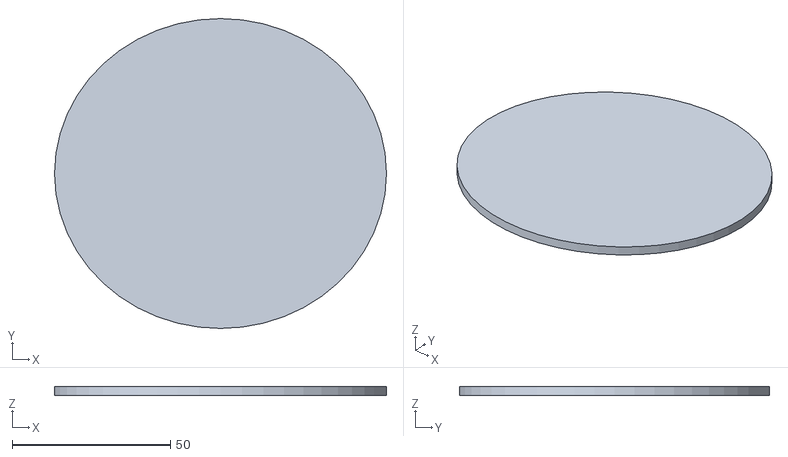
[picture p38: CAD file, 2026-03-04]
src/stl/cup_base.stl
105.0 x 98.0 x 3.00

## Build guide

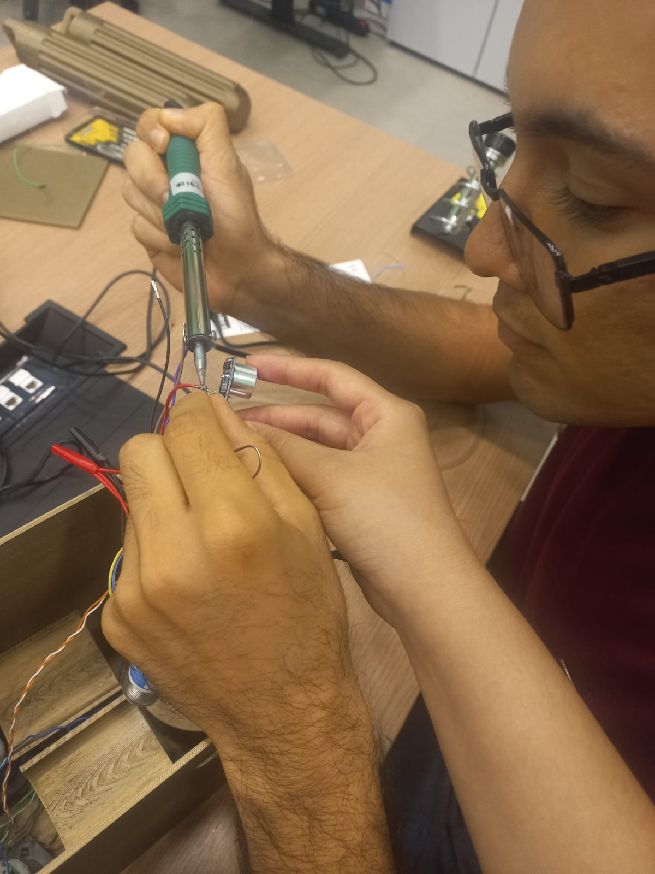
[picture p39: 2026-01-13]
docs/img/project3d-team-soldering.jpeg

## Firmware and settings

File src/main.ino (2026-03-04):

#include <Arduino.h> 
#include "Nextion.h"
#include "MachineLogic.h"

// ============================================================
// DEFINIÇÕES E CONFIGURAÇÕES
// ============================================================
// Define os estados da máquina de bebidas
enum MachineState {
  ST_INICIO,        // Estado inicial - aguarda inicialização
  ST_AGUARDA_MOEDA, // Aguarda inserção de moeda
  ST_AGUARDA_COPO,  // Aguarda colocação do copo
  ST_ESCOLHA,       // Aguarda escolha de bebida (café ou chá)
  ST_PREPARO_CAFE,  // Preparando café - enchimento em progresso
  ST_PREPARO_CHA,   // Preparando chá - enchimento em progresso
  ST_FIM_CAFE,      // Café pronto - aguarda retirada do copo
  ST_FIM_CHA        // Chá pronto - aguarda retirada do copo
};

// Estado atual da máquina
MachineState estadoAtual = ST_INICIO;

// --- Configuração de Pinos do ESP32 ---
// Sensores ultrassônicos para detecção de moeda
const uint8_t PIN_MOEDA_TRIG = 32;  // Pino de trigger (saída)
const uint8_t PIN_MOEDA_ECHO = 33;  // Pino de echo (entrada)

// Sensores ultrassônicos para detecção de copo
const uint8_t PIN_COPO_TRIG  = 19;  // Pino de trigger (saída)
const uint8_t PIN_COPO_ECHO  = 18;  // Pino de echo (entrada)

// Relés para controle dos motores de bomba
const uint8_t PIN_RELE_CAFE  = 25;  // Relé do motor de café
const uint8_t PIN_RELE_CHA   = 26;  // Relé do motor de chá

// Flag para lógica de ativação de relés (true = ativo em nível LOW)
const bool RELE_ATIVO_BAIXO = true;

// ============================================================
// OBJETOS DA TELA NEXTION
// ============================================================
// Páginas da interface HMI
NexPage page_initial    = NexPage(0, 0, "page_initial");   // Página inicial
NexPage page_moeda      = NexPage(1, 0, "page_moeda");     // Aguardando moeda
NexPage page_in_copo    = NexPage(2, 0, "page_in_copo");   // Aguardando copo
NexPage page_escolha    = NexPage(3, 0, "page_escolha");   // Escolha de bebida
NexPage page_cafe       = NexPage(4, 0, "page_cafe");      // Preparando café
NexPage page_cha        = NexPage(5, 0, "page_cha");       // Preparando chá
NexPage page_fim_cafe   = NexPage(6, 0, "page_fim_cafe");  // Café pronto
NexPage page_fim_cha    = NexPage(7, 0, "page_fim_cha");   // Chá pronto

// Botões da tela de escolha
NexButton bCafe         = NexButton(3, 2, "bCafe");  // Botão selecionar café
NexButton bCha          = NexButton(3, 3, "bCha");   // Botão selecionar chá

// Barras de progresso para visualizar enchimento
NexProgressBar bar_cafe = NexProgressBar(4, 2, "j0");  // Progresso do café
NexProgressBar bar_cha  = NexProgressBar(5, 2, "j0");  // Progresso do chá

// Lista de objetos que disparam eventos ao Nextion
NexTouch *nex_listen_list[] = {
  &bCafe,
  &bCha,
  NULL
};

// ============================================================
// FUNÇÕES AUXILIARES
// ============================================================

/**
 * Lê a distância em milímetros usando sensor ultrassônico HC-SR04
 * 
 * @param pinTrig - Pino de trigger (disparo do pulso)
 * @param pinEcho - Pino de echo (recepção da reflexão)
 * @return Distância em milímetros (sem uso de float para economizar memória)
 * 
 * Fórmula: (Duração * 10) / 58 = Distância em mm
 * (Equivalente a dividir por 5.8 usando apenas operações inteiras)
 */
int lerDistanciaMM(uint8_t pinTrig, uint8_t pinEcho) {
  digitalWrite(pinTrig, LOW);
  delayMicroseconds(2);
  digitalWrite(pinTrig, HIGH);
  delayMicroseconds(10);
  digitalWrite(pinTrig, LOW);

  // Aguarda o retorno do sinal (timeout de 30ms = ~5 metros)
  long duracao = pulseIn(pinEcho, HIGH, 30000);

  // Converte duração em milímetros (sem uso de float)
  return MachineLogic::calculateDistanceMM(duracao);
}

/**
 * Controla o estado de um relé (ligar/desligar motor)
 * 
 * @param pino - Pino do relé (GPIO)
 * @param ligar - true para ligar, false para desligar
 * 
 * Nota: A lógica XOR (^) com RELE_ATIVO_BAIXO inverte o sinal se necessário
 */
void controlarRele(uint8_t pino, bool ligar) {
  int nivelLogico = MachineLogic::getRelayLevel(ligar, RELE_ATIVO_BAIXO);
  digitalWrite(pino, nivelLogico);
}

// ============================================================
// CALLBACKS NEXTION (Interrupções de eventos)
// ============================================================

/**
 * Callback disparado quando o botão de café é pressionado
 * Altera o estado da máquina para preparar café
 */
void bCafePopCallback(void *ptr) {
  estadoAtual = ST_PREPARO_CAFE;
}

/**
 * Callback disparado quando o botão de chá é pressionado
 * Altera o estado da máquina para preparar chá
 */
void bChaPopCallback(void *ptr) {
  estadoAtual = ST_PREPARO_CHA;
}

// ============================================================
// LÓGICA DE NEGÓCIO
// ============================================================

/**
 * Processa o enchimento de bebida com monitor de copo
 * 
 * Responsabilidades:
 * - Controla o motor da bomba
 * - Incrementa a barra de progresso
 * - Detecta remoção do copo durante o processo
 * - Pausa e retoma automaticamente se copo for recolocado
 * 
 * @param barra - Referência à barra de progresso Nextion
 * @param pinoMotor - Pino do relé do motor (CAFE ou CHA)
 */
void processarEnchimento(NexProgressBar &barra, uint8_t pinoMotor) {
  int progresso = 0;
  barra.setValue(0);
  
  unsigned long tempoInicio = millis();
  unsigned long ultAtualizacao = millis();
  
  // Constantes de timing (em milissegundos)
  const unsigned long DURACAO_TOTAL = 26000;         // Duração total de enchimento
  const unsigned long TIMEOUT_SEM_COPO = 10000;      // Tempo máximo sem copo detectado
  const unsigned long INTERVALO_INCREMENTO = 1000;   // Intervalo para incrementar barra
  
  bool processoAtivo = true;
  
  Serial.println(F("Iniciando processo de enchimento..."));

  while (processoAtivo && progresso < 100) {
    // Processa eventos da tela Nextion
    nexLoop(nex_listen_list);

    // Timeout geral (evita travamento)
    if (millis() - tempoInicio > (DURACAO_TOTAL + TIMEOUT_SEM_COPO + 5000)) {
       processoAtivo = false;
       break;
    }

    // Lê distância do copo
    int distMM = lerDistanciaMM(PIN_COPO_TRIG, PIN_COPO_ECHO);

    Serial.print("Distancia: ");
    Serial.println(distMM);

    // --- Lógica de Detecção de Copo (62mm ≈ 6.2cm) ---
    if (MachineLogic::isCupPresentDuringFill(distMM)) {
      // Copo detectado
      delay(1000);
      controlarRele(pinoMotor, true);  // Liga o motor

      // Incrementa barra a cada 1 segundo
      if (millis() - ultAtualizacao >= INTERVALO_INCREMENTO) {
        progresso += 4;
        if (progresso > 100) progresso = 100;
        
        barra.setValue(progresso);
        ultAtualizacao = millis();
        
        Serial.print(F("Dist: ")); Serial.print(distMM); 
        Serial.print(F("mm - Progresso: ")); Serial.println(progresso);
      }
    } 
    else {
      // Copo removido - pausa o enchimento
      controlarRele(pinoMotor, false);  // Desliga o motor
      
      // Aguarda recolocação do copo por até TIMEOUT_SEM_COPO ms
      unsigned long inicioPausa = millis();
      bool copoVoltou = false;

      while (millis() - inicioPausa < TIMEOUT_SEM_COPO) {
        int d = lerDistanciaMM(PIN_COPO_TRIG, PIN_COPO_ECHO);

        Serial.print("Aguardando copo: ");
        Serial.println(d);

        if (MachineLogic::isCupCorrectlyPlaced(d)) { 
          copoVoltou = true;  // Copo foi recolocado
          break; 
        }
        delay(50);
      }

      // Se copo não retornou, encerra o processo
      if (!copoVoltou) {
        processoAtivo = false;
      }
    }
  }

  // Garante que o motor seja desligado ao final
  controlarRele(pinoMotor, false);
}

// ============================================================
// INICIALIZAÇÃO (SETUP)
// ============================================================

/**
 * Configura os periféricos e inicializa o sistema
 * - Abre comunicação serial
 * - Inicializa display Nextion
 * - Registra callbacks dos botões
 * - Configura pinos GPIO
 * - Desliga relés inicialmente
 */
void setup(void) {
  // Serial para debug (monitor serial)
  Serial.begin(115200);
  
  // Serial2 para comunicação com display Nextion (HMI)
  Serial2.begin(115200, SERIAL_8N1, 16, 17);

  // Inicializa display Nextion
  nexInit();
  
  // Registra callbacks para interação com botões
  bCafe.attachPop(bCafePopCallback, &bCafe);
  bCha.attachPop(bChaPopCallback, &bCha);

  // Configura pinos dos sensores ultrassônicos
  pinMode(PIN_MOEDA_TRIG, OUTPUT);
  pinMode(PIN_MOEDA_ECHO, INPUT);
  pinMode(PIN_COPO_TRIG, OUTPUT);
  pinMode(PIN_COPO_ECHO, INPUT);

  // Configura pinos dos relés como saídas
  pinMode(PIN_RELE_CAFE, OUTPUT);
  pinMode(PIN_RELE_CHA, OUTPUT);

  // Desliga todos os relés por segurança
  controlarRele(PIN_RELE_CAFE, false);
  controlarRele(PIN_RELE_CHA, false);

  // Exibe página inicial no display
  page_initial.show();
  Serial.println(F("Sistema Iniciado (Sensor em MM)"));
}

// ============================================================
// LOOP PRINCIPAL
// ============================================================

/**
 * Máquina de estados principal
 * Gerencia as transições entre os diferentes estados da máquina de bebidas
 */
void loop(void) {
  // Processa eventos da tela Nextion em todos os estados
  nexLoop(nex_listen_list);

  switch (estadoAtual) {
    
    case ST_INICIO:
      // Aguarda 2 segundos e passa para detecção de moeda
      delay(2000);
      estadoAtual = ST_AGUARDA_MOEDA;
      break;

    case ST_AGUARDA_MOEDA:
      // Mostra página de aguardar moeda
      page_moeda.show();
      
      // Aguarda detecção de moeda (distância < 25mm)
      while(true) {
        nexLoop(nex_listen_list);
        int distMM = lerDistanciaMM(PIN_MOEDA_TRIG, PIN_MOEDA_ECHO);
        Serial.print("Distancia moeda: ");
        Serial.println(distMM);
        
        // Moeda detectada quando distância < 25mm (2.5cm)
        if (MachineLogic::isCoinDetected(distMM)) {
          delay(500);  // Debounce
          break;
        }
        delay(50);
      }
      estadoAtual = ST_AGUARDA_COPO;
      break;

    case ST_AGUARDA_COPO:
      // Mostra página de aguardar colocação do copo
      page_in_copo.show();
      
      // Aguarda copo dentro da faixa de detecção (20-60mm)
      while(true) {
        nexLoop(nex_listen_list);
        int distMM = lerDistanciaMM(PIN_COPO_TRIG, PIN_COPO_ECHO);

        Serial.print("Distancia copo: ");
        Serial.println(distMM);
        
        // Copo detectado quando 20mm < distância <= 60mm
        if (MachineLogic::isCupCorrectlyPlaced(distMM)) break;
        delay(100);
      }
      estadoAtual = ST_ESCOLHA;
      break;

    case ST_ESCOLHA:
      // Mostra tela de escolha (café ou chá)
      page_escolha.show();
      
      // Aguarda escolha do usuário (callbacks atualizarão estadoAtual)
      while(estadoAtual == ST_ESCOLHA) {
        nexLoop(nex_listen_list);
        delay(50);
      }
      break;

    case ST_PREPARO_CAFE:
      // Mostra tela de preparo e inicia enchimento de café
      page_cafe.show();
      processarEnchimento(bar_cafe, PIN_RELE_CAFE);
      estadoAtual = ST_FIM_CAFE;
      break;

    case ST_PREPARO_CHA:
      // Mostra tela de preparo e inicia enchimento de chá
      page_cha.show();
      processarEnchimento(bar_cha, PIN_RELE_CHA);
      estadoAtual = ST_FIM_CHA;
      break;

    case ST_FIM_CAFE:
      // Café pronto - aguarda retirada do copo
      page_fim_cafe.show();
      while(MachineLogic::isCupStillPresent(lerDistanciaMM(PIN_COPO_TRIG, PIN_COPO_ECHO))) {
        delay(200);  // Verifica a cada 200ms
      }
      delay(2000);  // Aguarda 2 segundos adicionais
      estadoAtual = ST_AGUARDA_MOEDA;  // Volta para início do ciclo
      break;

    case ST_FIM_CHA:
      // Chá pronto - aguarda retirada do copo
      page_fim_cha.show();
      while(MachineLogic::isCupStillPresent(lerDistanciaMM(PIN_COPO_TRIG, PIN_COPO_ECHO))) {
        delay(200);  // Verifica a cada 200ms
      }
      delay(2000);  // Aguarda 2 segundos adicionais
      estadoAtual = ST_AGUARDA_MOEDA;  // Volta para início do ciclo
      break;
  }
}

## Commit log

2025-12-11 adicionado o arquivo principal ao esp32
2025-12-11 port map provisiorio
    portmap provisório para referência (fonte: https://i0.wp.com/randomnerdtutorials.com/wp-content/uploads/2018/08/ESP32-DOIT-DEVKIT-V1-Board-Pinout-30-GPIOs-Copy.png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")
2026-01-15 docs: add pin connection diagram image
2026-01-15 docs: update pin connection diagram
2026-01-15 chore: rename main file and overhaul project documentation
    - Rename src/main.cpp to src/main.ino for Arduino compatibility
    - Add FSM_Analysis documentation including state diagrams
    - Translate literature_comparison module
    - Update Doxygen configuration and fix image pathing
    [main.ino]
2026-01-19 docs: add 3D modeling documentation and update doxygen
    [Container_bottom_61mm.stl, Container_support.stl, Container_top_61mm.stl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]
